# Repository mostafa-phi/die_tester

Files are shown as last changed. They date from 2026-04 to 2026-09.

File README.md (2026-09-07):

# Die-tester_Stage-control
Python script to control Suruga stages for automatic fiber alignment to TFLN waveguides

## Setup Process
- Download the code onto your computer.
- Create a .venv environment.
- Install requirements.txt
- Make sure you have OBS Studio installed (and the appropriate drivers/software for the camera)

## Running
- The workfplow will be in main.ipynb. All the classes written by Eric (me) are in the `/src` folder. All the old code is in the `/reference_code` folder.

## Design documents
- [Die handling & edge-coupling concept study](docs/die_handling_concept_study.md) — architecture concepts for high-throughput handling of singulated 10 × 6 mm photonic dies (storage, indexing, and self-registering presentation to the fiber stages).
- [Month-1 prototype plan](docs/prototype_plan_month1.md) — what to build first, parts with lead times, week-by-week schedule and pass criteria for robotic die exchange on the existing tester.
- [Pick-and-place design note](docs/pick_and_place_design.md) — how the gripper holds the die (friction on the end faces, no toe), nose geometry, the pick/place sequences at the tray and the chuck with heights, forces and interlocks, die-present sensing, what the hand-cycling rig must measure.
- [Parts list](docs/parts_list.md) — one page sorting every part into purchase, machine (with material and process) and print (PPA-CF), with the CAD file for each.
- [Print list](docs/print_list.md) — every custom part with its STL, what is printed in PPA-CF for the prototype and what is machined, print orientation, holes to ream or tap, bolts, and the order to print in.
- [Month-1 bill of materials](docs/bom_month1.md) — exact part numbers, vendors, checked prices and lead times, plus the in-house vs outsourced die-sorting decision.
- [Interactive 3-D clearance model](docs/die_handling_3d.html) — three.js scenes of the full test-station exchange (CAD layout: nest, NanoMax fiber stages, microscope, Cartesian axes, wafer tray), tape pick, tray pocket and sorting station.
- [CAD package](cad/README.md) — parametric CadQuery models, one folder per component: [gripper](cad/gripper/README.md) (end-face die gripper: STEP/STL per part, SMC MHZ2-6D, tolerances, tuning), [nest](cad/nest/README.md) (self-registering, temperature-controlled chuck-and-cage chip stage), [tray](cad/tray/README.md) (112-pocket wafer tray, print file) and [station](cad/station/README.md) (full station with vendor models, clearance checks, layout and movement pattern). `python cad/build.py` regenerates everything; `CLAUDE.md` records the design rules and the folder-synchronization requirement.

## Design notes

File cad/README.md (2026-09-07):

# CAD package: one folder per component

Parametric CadQuery models of the die-handling redesign, built and kept in sync by one script.
Frame, die, contact rules and shared helpers are in `common/`; the rules for working here are in
[`../CLAUDE.md`](../CLAUDE.md).

| Folder | What | Depends on | Outputs |
|---|---|---|---|
| [`gripper/`](gripper/README.md) | end-face die gripper module: SMC MHZ2-6D, two arms, tip blocks, flexure blade, bracket; vertical (default) and horizontal (`_h`) layouts | `common` | per-part STEP/STL, assemblies, `checks[_h].txt`, renders |
| [`nest/`](nest/README.md) | self-registering, temperature-controlled chip stage: copper vacuum chuck, Semitron cage with stop pads and guards, T-riser with TEC, on the die stage (MISUMI RMPG40W-N rotary on a Suruga KXC04015-C X stage on a KB1X1) | `common`, `gripper` | part STEP/STL, assemblies (seated / set-down), `checks.txt` incl. the moving-nest sweep, renders |
| [`tray/`](tray/README.md) | 8 × 14 wafer tray with nose-slot pockets | `common`, `gripper` | print STL, pocket check STEP, `checks.txt`, renders (full-tray STEP ignored) |
| [`station/`](station/README.md) | full station: nest, gripper, MISUMI LX20 X/Z/Y actuators with their risers, tower bracket and arm, NanoMax fiber stages, microscope, tray; clearance checks; layout and movement pattern | all of the above | `checks[_h].txt`, renders (assemblies ignored, ~100 MB) |
| `vendor/` | manufacturer STEP (tracked) and the fetch script; see `vendor/README.md` | | |

## Build

```bash
python cad/build.py            # gripper (+ _h) -> nest -> tray -> station (+ _h) + renders, writes build_manifest.json
python cad/build.py --check    # exit 1 if any source changed since the last build or a tracked output is missing / edited
```

Manufacturer STEP in `cad/vendor` is placed wherever the file exists; without it the
envelope is used and the checks say so in their first line. There is one station build (plus the
`_h` horizontal-gripper variant kept for comparison), not separate envelope and vendor builds.
Every `model.py` can also be run on its own (`python cad/nest/model.py`) while iterating, but the
manifest is only written by a full build, and `--check` (run at every session start) fails until
one has been done. Commit sources, checks, renders, small STEP/STL and the manifest together.

Needs `cadquery` (full OCP build) and, for the renders, `cadgen` from the vendored skills
(`.claude/setup_cad_skills.sh` installs both).

## Reading the checks

`checks*.txt` list axis-aligned-bounding-box separations per member pair: positive = clear by that
much, OK above the stated margin, TIGHT below it, OVERLAP negative. Each README states which non-OK
lines are intended (a stop pad touching the seated die, the gripper band passing under the
objective). Anything else is a defect to fix in the model, never in the text.

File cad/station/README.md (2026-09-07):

# Full station assembly: layout, movement pattern, compatibility

`model.py` (CadQuery) → `STEP/station_assembly[_h].step` (git-ignored, ~100 MB), `checks[_h].txt`, `renders/`.
Rebuild with `python cad/build.py` (builds the default and the `_h` horizontal-gripper variant). Manufacturer
STEP from `cad/vendor` is placed wherever the file exists and the envelope is used otherwise, so a clone
without the vendor files still builds and checks; the first line of `checks.txt` lists the
vendor files that were placed. Imports `cad/gripper`, `cad/nest`, `cad/tray` and `cad/common`; this file
only **places** the components and adds the transport axes, the two NanoMax fiber stages with holder
envelopes, the microscope envelope and the table, then computes the clearances.

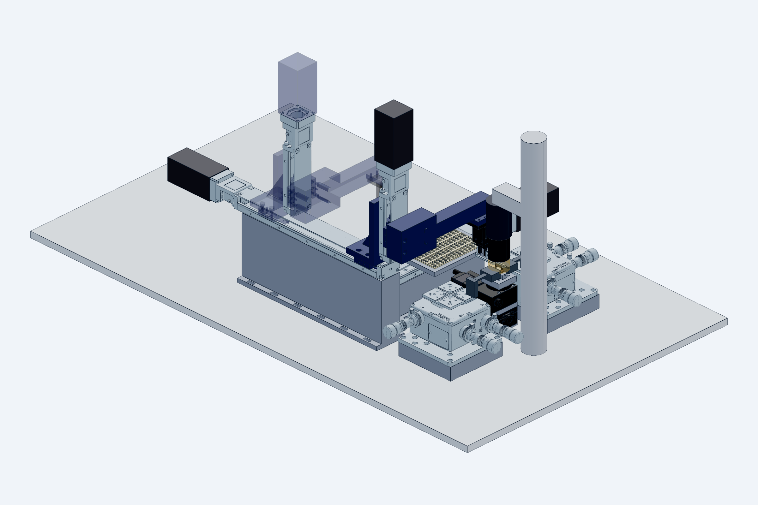
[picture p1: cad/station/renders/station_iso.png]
station

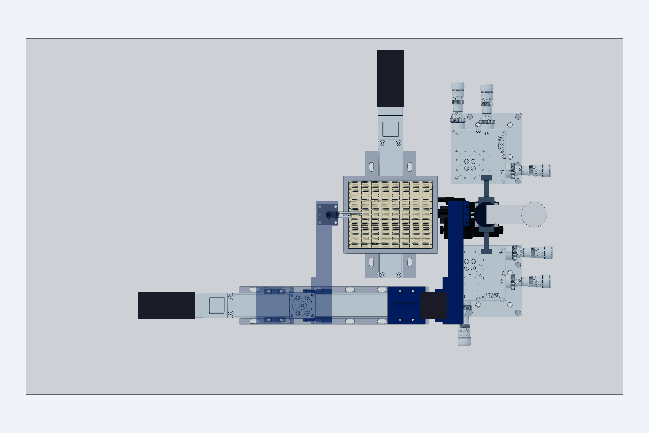
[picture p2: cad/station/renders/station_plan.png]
plan

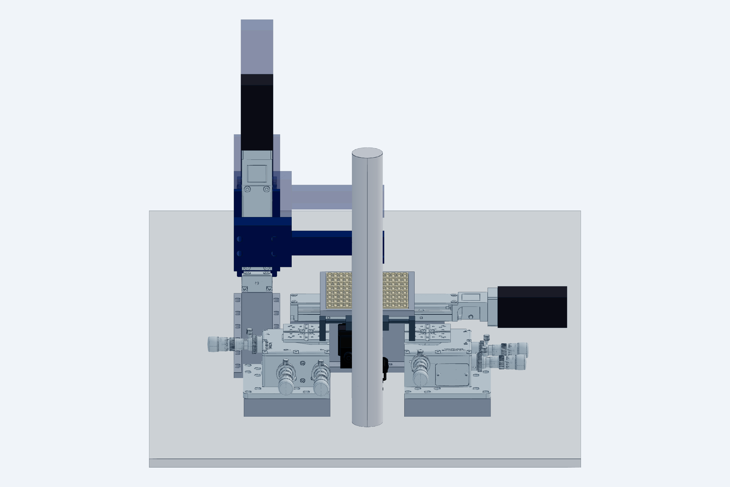
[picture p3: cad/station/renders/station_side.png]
side


## Manufacturer models

| Part | File in `cad/vendor` | Status |
|---|---|---|
| Thorlabs NanoMax 300, MAX313D/M (×2) | `thorlabs_MAX313D_M.step` | **placed**; the input stage is rotated −90° so its Z micrometer (46 mm out of the +X face) points −Y and its Y micrometers +X. A left-handed NanoMax would allow the mirror layout. |
| Thorlabs KB1X1 kinematic base | `thorlabs_KB1X1.step` | **placed** under the nest riser (25.4 × 25.4 × 12.7 mm assembled) |
| MISUMI **LX2005CG-B1-A2040-300** (X), **-200** (Y), **-100** (Z) single-axis actuators | `misumi_LX2005CG-B1-A2040-{300,200,100}.step` | **placed** (`lx_file_members()`: body with the motor-bracket casting + cover strip, table plate, adapter plate + screws; the motor is an envelope on the plate). The files confirmed the catalog reading: 40 wide × 26.5 tall body, 52 × 57 table plate to 27 above the rail bottom, screw axis at 13, bracket casting 56 beyond the rail, 40 × 40 × 13 adapter plate hanging 7 mm below the rail. Effective stroke = L − 63.5. The uploaded files carry the A2040 (□40 servo) adapter plate; the actuators are ordered with the T2042 plate for the Oriental Motor AZM46 steppers (decided; same outline). |
| SMC MHZ2-6D-M9N | `smc_MHZ2-6D.step` | **placed** through `cad/gripper` (fingers set from the drawn open position to closed) |
| Suruga KXC04015-C X stage | `suruga_KXC04015-C.step` | **placed** through `cad/nest` (motor and cable toward −X; `checks.txt` checks base, table, motor and cable loop per member) |
| MISUMI RMPG40W-N motorized rotary | `misumi_RMPG40W-N.step` | **placed** through `cad/nest` on top of the X stage (motor toward −X, long end toward −Y; straight vendor cable cut at a 40 mm lead-out; rides ±7.5 mm with the stage). The earlier RMPG60ZC-N upload is the vertical-axis type and is not used |
| Microscope objective / tube / column | — | envelope (`common.OBJ_WD`, `OBJ_DIA`, `TUBE_DIA`); measure |

The Velmex BiSlide files (`velmex_MN10-*.step`) are no longer used: the transport was re-sized to what the
handling needs (±0.15 mm at the nest, ±0.3 mm at the tray, ±0.05 mm in Z, every position approached from the
same side) and moved to the LX20 class for cost and speed; see `docs/bom_month1.md` A1.

## Layout (frame: X = die long axis, Y = optical axis, Z up, die bottom at nest = 0)

| Element | Position | Why |
|---|---|---|
| Optical table plane | Z −111 | NanoMax on a 25 mm riser + deck 62.5 + platform 4 + holder 20 puts the fiber axis at die-top height (Z 0.5); the riser exists because the die-stage stack needs 100 mm under the die. |
| Nest (`cad/nest`) on its **die stage** | T-riser neck X −8…18, Y −2…8 down to Z −12, 38 × 38 wide body to Z −22.3 on a **MISUMI RMPG40W-N** motorized rotary (axis through the die, motor toward −X, body toward −Y, on an 8 mm spacer) on a **Suruga KXC04015-C** X stage (±7.5 mm, motor toward −X) on a KB1X1; copper chuck; Semitron cage X −2.5…12.5, Y −2…8 | Narrow at the top so both fiber corridors stay open; the nest steps the die from device to device under fixed fibers; the rotary above the travel nulls the fiducial-to-fiducial yaw; the gripper meets it at stage home only. |
| NanoMax 300 (input / output) on 25 mm risers | inner faces 45 mm from the facets: Y −157…−45 and Y 51…163; X −51…61 | Fiber holders reach in from the platforms; holder fronts 5 mm from the facets. |
| Microscope | objective Ø34 centred on the die, front lens at WD 20; Ø40 tube above; arm to a Ø40 column at **X = 80** | Behind the nest, as on the bench. |
| **X actuator** (LX2005CG L 300, stroke 236.5; 208.7 used) | along X, centre-line **Y = −140**; rail X −385…−85 with its bottom at Z 7.2 on a **118 mm riser bar** (40 wide, under the base rail; the bracket casting, adapter plate and motor overhang to X −544) | Its 52 mm band (Y −166…−114, the table plate) lies beside the tray's Y sweep (deck to Y −108 at the extreme row) and beside the input NanoMax (X ≥ −51), so nothing passes under it and the riser is one bar, no bridge. Travel margins 25.3 mm at the far column, 2.5 mm after the push-to-stop. |
| **Z actuator** (LX2005CG L 100, stroke 36.5; 20 used) | vertical on a 60 × 60 × 10 angle bracket bolted to the X table plate (4 × M4); rail mounting face on the bracket's +X leg, rail Z 44…144, adapter plate and brake motor up to Z ≈ 303; table plate centre at Z 90.5 at the nest (76…112.5 available) | Only 8 mm lift + 12 mm drop are needed; the ball screw back-drives, hence the brake motor (or a pneumatic slide, see the design note). |
| **Arm** | one piece: 33-deep adapter block on the Z table plate (4 × M4 counterbored + 2 dowels), 25 mm square bar along +Y from the axis band to the die line at Z 78–103, 8 mm end plate over the gripper interface (`gripper.IFACE`) at Z 70–78 | X-table centre at the nest is **−121**: the bar starts exactly at the interface's −X edge, so there is no bar along X and no drop bar. Nothing of the arm enters the objective footprint. Static moment on the X table 0.9 N·m against 27 allowable. |
| **Gripper module** (`cad/gripper`) | actuator body X −40…−20, Y −2…8; bars 5 mm above the die | Only the two 3 mm bars and the tip blocks enter the objective footprint. |
| **Y actuator** (LX2005CG L 200, stroke 136.5; 97.5 used) + **wafer tray** (`cad/tray`) | along Y under the tray at X −146 (tray centre), rail Y −97…+103, motor toward +Y (adapter plate to Y 172, motor envelope to 262); rail bottom at Z −48 on a **63 mm riser bar**; deck on the table plate, tray ledges at **Z −12** | Columns at die X −95 … −207 (16 mm pitch), rows at 7.5 mm pitch; X selects the column, Y the row. Column 0 sits where the tray's +X rim and the deck clear the input NanoMax base as the rows sweep (21 / 13 mm). Travel margin 19.5 mm at both rows. |

`checks.txt` prints the derived numbers (rail positions, travel margins at both ends of every actuator, the
static moment on the X table plate against the LX20's 27 N·m rating, the exchange time at 200 mm/s).

## Custom mounting parts (`STEP/`, `STL/`)

The pieces between the actuators and everything else are real parts with bolt patterns (measured in the
LX20 STEP files: base holes Ø3.4 in two rows 18 mm apart on a 60 mm pitch, table plate 4 × M4 on 20 × 45 with
two Ø3 dowels) and are exported per part; the printing and finishing instructions are in
[`docs/print_list.md`](../../docs/print_list.md). Hole sizes are tap-drill / press-fit for printing.

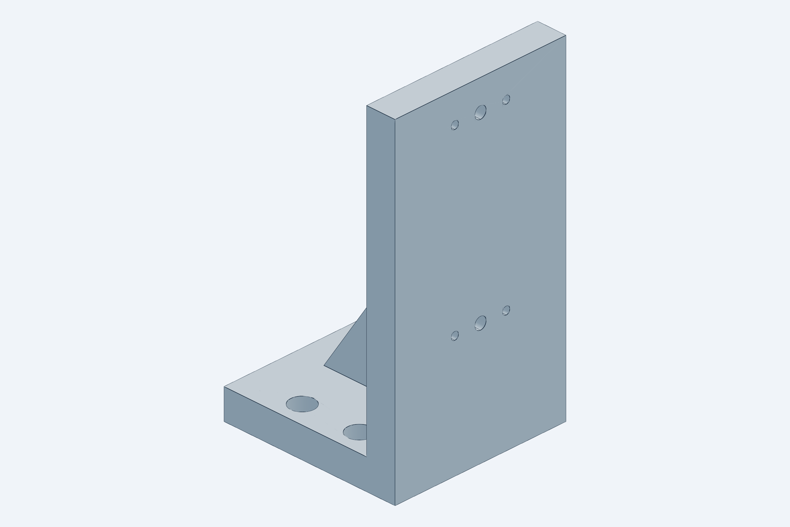
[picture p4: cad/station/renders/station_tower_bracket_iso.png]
tower bracket

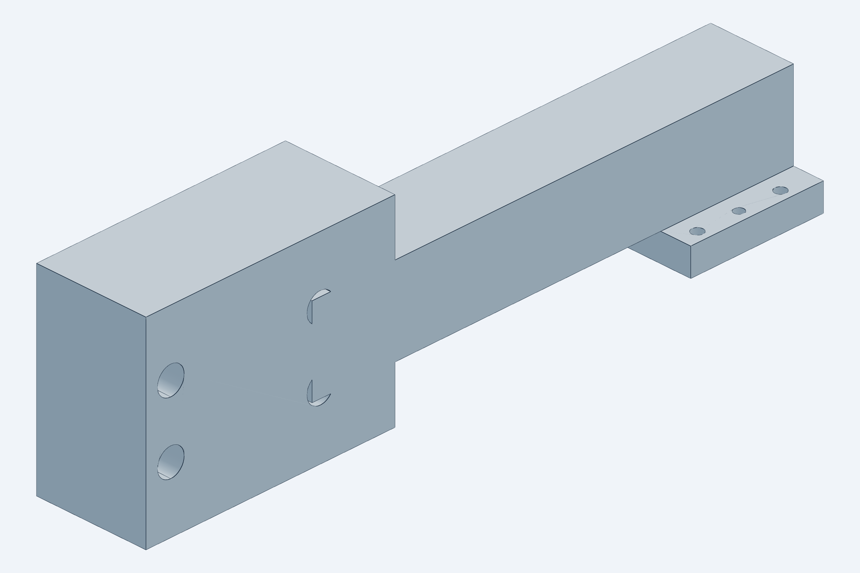
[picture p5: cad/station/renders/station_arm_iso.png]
arm

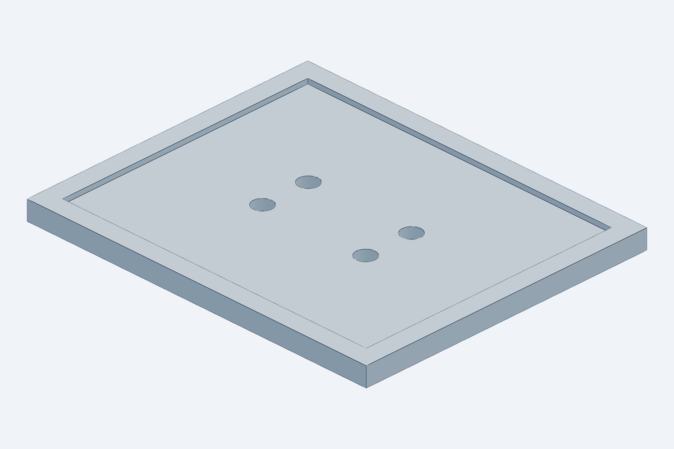
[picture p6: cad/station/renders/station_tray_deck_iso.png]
tray deck

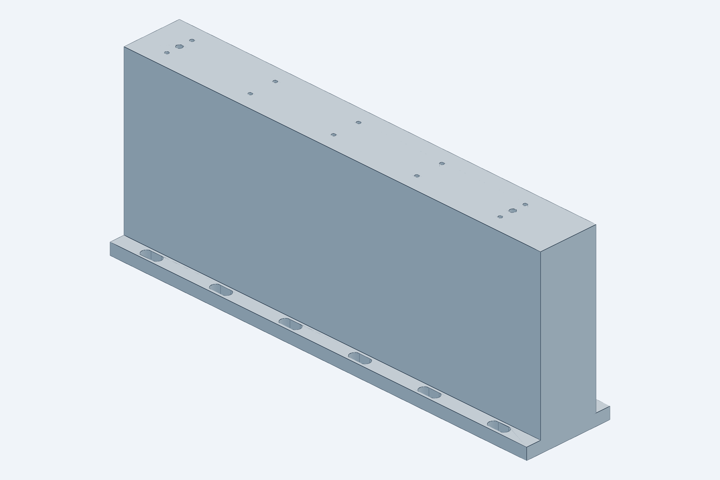
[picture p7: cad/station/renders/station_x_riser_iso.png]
X riser


| File | Part | Interfaces |
|---|---|---|
| `x_axis_riser_6061[_h]` | riser bar under the X actuator: 40 wide body from the table to the rail bottom, 60 × 8 foot flange with 6.6 × 14 slots on a 50 mm pitch | top: 10 × M3 tap-drill + 2 × Ø4 pin holes on the LX20 base pattern; foot: M6 or ¼-20 on a 25 mm / 1″ grid |
| `y_axis_riser_6061` | same under the Y actuator (80 wide flange) | 6 × M3 + 2 × Ø4; foot slots |
| `tower_bracket_6061` | 60 × 60 × 10 base on the X table plate, 10 mm leg carrying the Z rail, gusset rib | base: 4 × Ø4.5 counterbored + 2 × Ø3 dowels (table pattern); leg: 4 × M3 tap-drill + 2 × Ø4 pins (Z rail base pattern) |
| `arm_6061[_h]` | one piece: 33-deep adapter block on the Z table plate, 25 sq bar along +Y, 8 mm end plate over the gripper bracket | block: 4 × Ø4.5 counterbored Ø8 from the outside + 2 × Ø3 dowels; end plate: 4 × M4 tap-drill + 2 × Ø3 dowels on `gripper.IFACE` |
| `tray_deck_6061` | 8 mm deck on the Y table plate with a 2 mm locating pocket for the tray (0.2 mm clearance per side) | 4 × Ø4.5 counterbored from the pocket floor + 2 × Ø3 dowels |
| `nanomax_riser_6061` (×2) | 25 mm plate under each NanoMax | 16 × Ø6.6 through on the 25 mm grid (M6 bolts through the stage slots into the table) |

## Movement pattern (one exchange)

Coordinates are X-table centre / Z-table height of the arm bar / Y-stage pocket position.
Fibers are only ever moved by their own NanoMax stages.

| Step | Axis | From → to | Interlock |
|---|---|---|---|
| 0 | die stage X (KXC04015) | nest to its **home** position (stage origin sensor) | home flag set; the gripper never enters otherwise |
| 1 | NanoMax Y (both) | fibers retract 1.0 mm along ±Y | fibers-retracted flag set |
| 2 | Z | +8 mm (arm end plate Z 70 → 78), gripper open | fibers retracted, objective gap ≥ 11 mm |
| 3 | Z | −8 mm: noses descend beside the die's end faces | — |
| 4 | gripper | close (finger-on-finger stop; 0.32 N on the die) | — |
| 5 | nest | chuck vacuum off; **Z +8 mm** lifts the die | vacuum switch reads atmosphere |
| 6 | X | −121 → −216 … **−328** (column *c* of the tray: 95 + 16·c mm along the die's long axis) | Z at +8 |
| 7 | Y stage | brings row *r* to Y = 3 (±48.75 mm) | can pre-position during step 6 |
| 8 | Z | −8 −12 mm: die onto the pocket ledges (12 mm below nest height) | — |
| 9 | gripper | open (+1.5 mm per side) | — |
| 10 | Z | +20 mm; then steps 6–9 in reverse with the next die, arriving at the nest with the die's +X end face **0.2 mm short of the stop pads** | — |
| 11 | Z, gripper | Z −8 mm: die onto the chuck pad; jaws open (+1.5 mm per side) | — |
| 12 | X | **push-to-stop: gripper +1.7 mm** — the open near nose meets the die's −X end face, slides it 0.2 mm onto the two +X pads and overtravels 0.1 mm, so the blade limits the push to 0.25 N; X and yaw are now mechanical | — |
| 13 | nest, X, Z | chuck vacuum on (seat detection); gripper −1.7 mm, Z +8 mm, X out to the park position; camera pose check; fibers approach | vacuum switch reads seated |
| 14 | die stage X, θ | yaw trim: X to the fiducial at one die end, then to the other, camera reads the lateral offset, θ rotates it out (repeat once); then X steps the die ±4 mm to bring each device under the fibers (fibers realign per device; the stage stays inside the fence while the gripper is parked) | gripper parked |

Exchange time budget: ~8 s; the two X moves of 207 mm at 200 mm/s take ~1.3 s each, the rest is Z, the
jaw cycles and the vacuum settling.

## Compatibility results (`checks.txt`, vendor files placed)

All pairs are OK or TIGHT-by-design. Intended non-OK lines: the gripper band sweep passes under the
objective (that *is* the exchange; the bar-height check is `cad/gripper/checks.txt`), the stop pads touch
the seated die, and the fiber envelope 1.9 mm above the cage plate.

- **Microscope:** finger bars 12.0 mm below the objective front lens (WD 20); near head 11.0 mm;
  actuator body 8 mm outside the barrel and 5 mm outside a Ø40 tube; arm end plate and bracket 7 mm
  outside the tube; nothing within 44 mm of the column. If the tube above the objective is wider than
  Ø40, move the actuator further out with `body_cx`; the arms lengthen by the same amount.
- **Fiber stages and holders:** gripper arms 3.2 mm from the holder bodies at the nest; the X rail's nest end
  25 mm from the input NanoMax base and its band beside it in Y; the tower and the arm pass above the NanoMax
  and the holders. The die's travel path (after the 8 mm lift) clears both holders and never crosses the fiber line.
- **Die stage:** every stack member 17 mm below the holder bodies, 10 mm from the input NanoMax base and 28 mm
  from the output one; both motors, toward −X, keep 87 mm and more to the microscope column; the moving nest
  keeps 3.0 mm to the holders at the travel ends.
- **Tray side:** tray rim 21 mm and deck 13 mm from the input NanoMax base at the extreme row; the deck 6 mm
  from the X band; the tower at the farthest column clear of the Y actuator, its riser and the X motor plate;
  travel margins ≥ 2.5 mm at every actuator end (printed in `checks.txt`). The tower base plate sits 0.5 mm above
  the X body (TIGHT by design: the table plate top stands 0.5 above the cover strip).

Real collisions the model found and the layout absorbed: NanoMax Z micrometer vs X axis (input stage
rotated −90°), riser vs the 5 mm-protrusion fiber holders (10 mm neck), and, in the Velmex layout this one
replaces, the Y stage passing under the X axis (two pedestals) and the horizontal arm through the X axis
(drop bar): both disappear with the X actuator's narrow band beside the tray sweep.

## Open dimensions to measure before ordering the risers and brackets

1. Fiber axis height above the NanoMax platform (`holder_axis_above_deck`, assumed 20): sets every riser height together with the 25 mm NanoMax riser (`common.NANOMAX_RISER`).
2. Objective working distance and the diameter of whatever sits above it (`common.OBJ_WD`, `TUBE_DIA`).
3. The real fiber holder (`common.FIBER`).
4. The AZM46 motor bodies on each LX20 (the model's motor envelope is 42 sq × 90 long, which covers the AZM46MK brake motor on Z and the AZM46AK on X and Y with margin) and their cable exits.
5. KXC04015 and RMPG40W-N bolt patterns for the two adapter plates (from their STEP files); the KB1X1 platform pattern.

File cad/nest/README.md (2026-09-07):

# Nest (chip stage): self-registering, temperature-controlled

`model.py` (CadQuery) → `STEP/`, `STL/`, `renders/`, `checks.txt`. Rebuild with `python cad/build.py`.
Imports `cad/gripper` (the jaws for the clearance checks) and `cad/common` (die, contact rules,
fiber-holder envelope `FIBER`, bench levels `TABLE_Z` / `KB1X1_H`). Used by `cad/station` (`levels()`,
`stack()`, `riser()`, `chuck()`, `cage()`, `cage_parts()`, `moving_members()`, `tec()`, `N`).

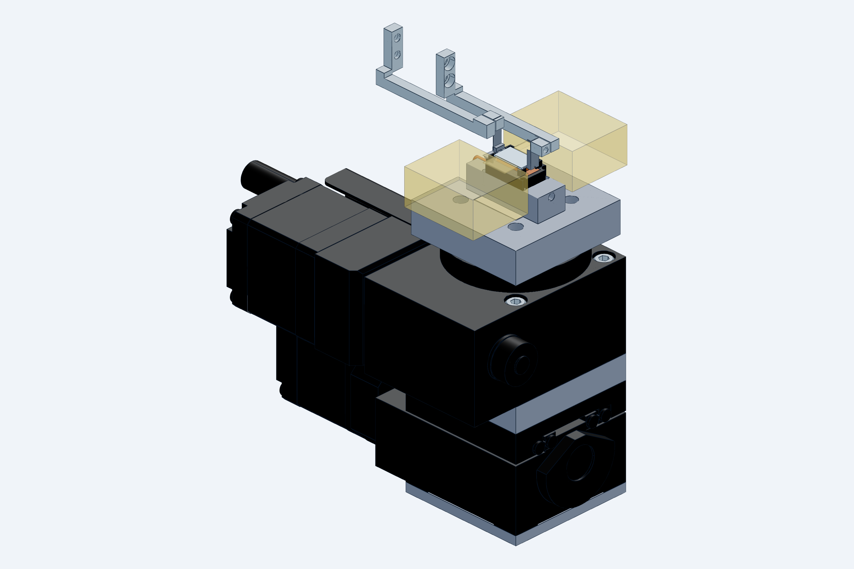
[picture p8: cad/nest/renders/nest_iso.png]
nest

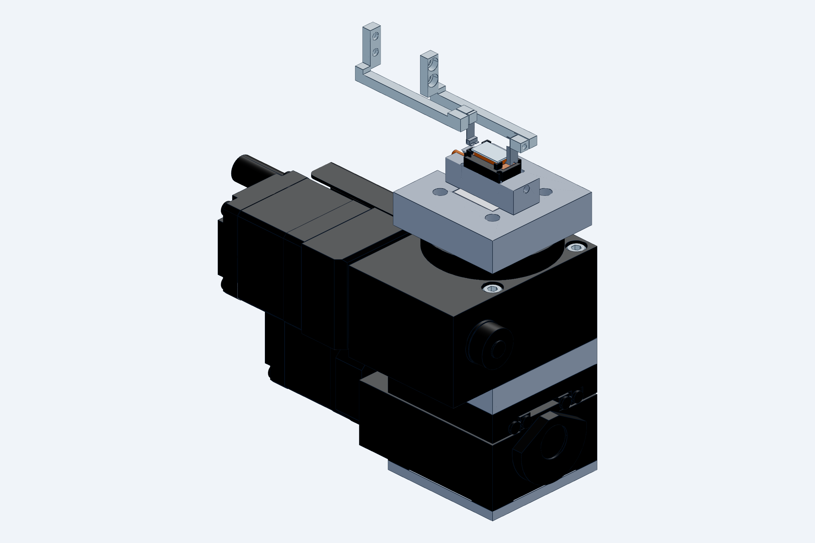
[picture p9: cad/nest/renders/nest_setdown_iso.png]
set-down, jaws open


## What it does

The gripper sets the die down on a lapped copper vacuum-chuck pad 0.2 mm short of two hard-stop pads,
opens, and pushes the die onto the pads with its own compliant nose (**push-to-stop**). The pads fix X and
yaw, the pad fixes Z, pitch and roll; Y is left free for the fiber stages (which measure the gap anyway)
and caged to ±0.6 mm. Nothing touches the facets or the top surface; only the two stop pads and the chuck
ever touch the die.

| Axis | Mechanism |
|---|---|
| Z, pitch, roll | lapped copper chuck pad (flat ≤ 3 µm), 9 × 5 mm = 75 % of the backside, 0.5 mm inboard of every edge |
| X, yaw | two Semitron ESd 480 **stop pads** on the +X end face (Y 0.6–1.2 and 4.8–5.4, 0.6 mm in from the facets, contact band Z 0.05–0.30): yaw from a 4.2 mm base ≈ 0.03° |
| Y | free; **corner guards** 0.6 mm outside each facet plane only at X ≤ 0.5 and X ≥ 9.5 where no fiber goes, plus an X guard 0.4 mm behind the −X end face |

Milling cannot make a sharp inside corner, and the die's corners are not trusted either: the stop pads
are 0.6 mm from the facets and the 0.2 mm relief between pad and guard keeps the die corner in free
space. The die registers on two pads and a plane, never in a corner.

**Push-to-stop numbers** (`checks.txt`): set down 0.2 mm short, jaws open (+1.5 mm per side), gripper
indexes +1.735 mm in X; the open near nose meets the −X end face, slides the die 0.2 mm onto the pads and
overtravels 0.10 mm, so the flexure blade limits the push to 0.25 N. Vacuum on, jaws retract. The camera
then reads Y and confirms X (a die that stuck to the chuck stops short and is caught there).

## Die stage: the nest moves

The devices span about 8 mm along the die, the NanoMax fiber stages travel only 4 mm, so the die is
stepped from device to device by moving the nest, as the current tester does with its centre stage.
One X move keeps both fibers registered to each other. The gripper meets the nest only at the stage
**home** position; the exchange sequence homes the stage first and the software fence enforces it.

The stack needs 100 mm under the die, so the two NanoMax stages and the Y stage sit on **25 mm riser
plates** (`common.NANOMAX_RISER`) and the table plane is at Z −111; the fiber axis stays at Z 0.5.

| Level (bottom up) | Part | Z (table = −111.0) |
|---|---|---|
| kinematic base | Thorlabs KB1X1 (2374-E0W), 25.4 sq × 12.7 | −111.0 … −98.3 |
| adapter | `STEP/nest_adapter_kb_kxc.step`, 6061, 3 mm: KB1X1 platform pattern → 4 × M3 tapped on the X stage's 32 × 32 base holes | −98.3 … −95.3 |
| X stage | **Suruga KXC04015-C** (crossed-roller, 40 × 40 table, 30 tall, 15 mm travel, ball screw Ø6 × 1 mm lead, 2 µm full / 1 µm half step, ±0.2 µm repeatability, 0.31 kg, 5-phase stepper on the DS102): motor section 59 mm toward −X, its 28 mm motor box 4 mm above the table top. **Vendor STEP placed** (`cad/vendor/suruga_KXC04015-C.step`): it confirms the table's 8 × M3 on a 16 mm grid with a Ø4 centre pin and the base's 4 × Ø3.5 on 32 × 32; the cable loop reaches Y +31 behind the motor, the base solid runs 11 mm further toward the motor than the catalog outline | −95.3 … −65.3 |
| spacer | `STEP/nest_spacer_kxc_rot.step`, 6061, 8 mm on the X-stage table: 4 × Ø3.4 for the rotary's M3 bolts into the table's M3 grid, Ø4 dowel at the centre (table pin hole → rotary bore) so the rotation axis sits on the die centre. Needed because the rotary's worm housing starts 2.6 mm above its base and its cable lead-out dips 2.1 mm below it, while the X stage's motor box stands 4 mm above the table top | −65.3 … −57.3 |
| rotary | **MISUMI RMPG40W-N** motorized worm-gear rotary, horizontal table, **on the X stage**: body 40 × 55 × 35 tall with the axis through the die centre, 20 mm from the short end; 39 sq table with 8 × M2 on a 10 mm grid and a Ø8 bore; 28 mm 5-phase stepper on the DS102's second axis; motor toward −X, long end toward −Y; rides ±7.5 mm with the X stage (worm housing 6.6 mm and cable 1.9 mm above the X-stage motor box at the −7.5 end). **Vendor STEP placed** (`cad/vendor/misumi_RMPG40W-N.step`) | −57.3 … −22.3 |
| riser | `STEP/nest_riser_6061.step`: 38 × 38 wide body (4 × M2 counterbored at ±10 into the rotary table, TEC pocket, wire channel) to Z −12, then the 10 mm neck to the cage plate | −22.3 … −4.5 |

**Why the rotary sits on top of the X stage.** Yaw is measured by driving the X stage from the
fiducial at one end of the die to the fiducial at the other end under the fixed microscope and reading
the lateral offset. To first order that offset is the die length times the angle between the fiducial
line and the **stage travel direction**; the travel's own angle to the bench cancels because the same
travel carries both fiducials. The rotary must therefore turn the die relative to the travel, which it
can only do above the X stage: below it, die and travel would turn together and the offset would not
change. Device stepping then shifts the next waveguide laterally by pitch × (die-vs-travel yaw) only, so
once the procedure has nulled it the fibers see no drift; the travel's residual angle to the fiber axes
(a mounting error under a degree) costs only the negligible angular coupling loss. The rotary is
motorized (worm gear, on the DS102 axis the current centre stage's θ uses), so the trim runs per die.
Dicing squareness between the end face and the facet is the floor no stage can remove. The rotary's
straight cable in the vendor file reaches 179 mm out along −X, which would run into the Y-stage riser;
it is routed down after a 40 mm lead-out (only that lead-out is modelled) and flexes ±7.5 mm with the
stage.

**Travel used.** ±4 mm of the ±7.5 available brings any waveguide at die X 1 … 9 under a fiber fixed
at station X 5. `checks.txt` sweeps the stage from −7.5 to +7.5 and reports the worst clearance of every
moving member (neck, wide body, cage plate, corner blocks, chuck, stage table) against the fixed fibers
and holder bodies: the corner blocks come within 0.4 mm of a fiber at ±4 (their tops are 0.30, 0.09 below
the fiber envelope), the neck and cage plate keep 3.0 mm to the holders at any offset, the riser keeps
5.5 mm to the motor box at −7.5. Both motors point −X because +X is the microscope column and ±Y are the
fiber stages (the station checks confirm 87 mm and more to the column, 10 mm to the input NanoMax base).

**Thermal note.** The riser's wide body is 10.3 mm thick on the rotary table, so the rotary and the
X stage become part of the TEC's hot-side path. Fine below ~2 W; above that put a copper spreader with a
thermal break under the riser or take the heat off with a water block rather than into the stage.

## Fiber access

The fiber tips protrude ~5 mm from their holders (`common.FIBER`), so the holder bodies come to Y −5 and
Y +11 (facets at Y 0 / 6), 25 mm wide, from 8 mm below to 4 mm above the fiber axis (envelope; measure
the real holder). Nothing of the nest may be in that space: the riser is a **10 mm wide neck** (Y −2…8)
from the cage plate down to Z −12, below the holders' underside, and only then widens to 26 × 26 mm for
the TEC and the KB1X1 base. Checked: cage and neck 3.0 mm from the holder faces, chuck block 5.5 mm, wide
body 4 mm under the holders; gripper arms 3.2 mm from the holders at the nest.

## Thermal and vacuum

The chuck is a C101 copper block (Ni-plated, pad lapped after plating): a 9 × 5 mm pad island on a
13 × 4.8 mm block whose neck passes through the cage plate and the riser (0.3 mm air gap all round) to a
**15 × 15 × 2.5 mm TEC** in the riser's wide section at Z −12; the aluminium riser is the hot-side heat
sink (add fins or a water block on the wide section above ~2 W). Thermistor bore Ø1.0 × 5 deep from the
+X face at Z −6. **Vacuum**: 6 × Ø0.5 holes in the pad into a 7 × 4 × 1 mm plenum, bore to a Ø1.5 stub
tube leaving the −X face at Z −6 through a clearance hole in the riser neck (no seal between copper and
riser); silicone hose to the M5 fitting.

## Parts

| File (STEP; the STL of every part is in `STL/`, see `docs/print_list.md`) | Material | Make | Notes |
|---|---|---|---|
| `STEP/nest_chuck_copper.step` | C101 copper, Ni plate | CNC + lap | pad island, vacuum holes, plenum, neck, stub tube, thermistor bore |
| `STEP/nest_cage_semitron.step` | Semitron ESd 480 | CNC | one piece: plate with the copper window, 4 corner blocks (stop pads, X guard, Y guards); 2 × M2 + 2 × Ø1.5 dowels to the riser |
| `STEP/nest_riser_6061.step` | 6061 | CNC | T-riser: neck, 38 × 38 wide body with the TEC pocket, wire channel, vacuum-stub and thermistor clearances, 4 × M3 counterbored to the KXC04015 table |
| `STEP/nest_adapter_kb_kxc.step`, `STEP/nest_spacer_kxc_rot.step` | 6061 | CNC / waterjet | 3 mm adapter plate between the KB1X1 and the KXC04015-C base (the stage's pattern confirmed in the vendor STEP; the KB1X1 platform pattern still to confirm) and the 8 mm spacer with the centre dowel between the X-stage table and the rotary |
| — | Suruga KXC04015-C X stage, MISUMI RMPG40W-N rotary, TEC 15 × 15 × 2.5, thermistor, KB1X1 (Thorlabs 2374-E0W) | buy | both stages run on the existing DS102 controller #3 (today's centre-stage X and θ axes) |

Assemblies: `STEP/nest_module_assembly.step` (die seated, jaws closed, fiber/holder envelopes, full
stack) and `STEP/nest_module_setdown.step` (jaws open at the set-down position). `checks.txt` lists every
clearance: corner blocks vs die (seated / set down / Y-offset), vs the jaws closed / open / during the
push, nest vs fiber and holder envelopes, holders vs the gripper, and the moving-nest sweep. Expected
non-OK lines: the two stop pads TOUCH the seated die (by design).

## Open items (measure on the bench)

- Real fiber-holder envelope (width, height below/above the fiber axis, front-face-to-tip): `common.FIBER`.
- RMPG40W-N resolution and repeatability from the MISUMI datasheet (not in the STEP); the KB1X1 platform bolt pattern for the adapter plate.
- TEC part number, heat load and whether the riser needs a water block.
- Die backside finish (vacuum seal on a lapped pad needs it flat and clean).

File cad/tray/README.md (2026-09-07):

# Wafer tray

`model.py` (CadQuery) → `STL/wafer_tray_8x14.stl` (the print file), `STEP/tray_pocket_check.step`,
`renders/`, `checks.txt`; the full-tray STEP (5.6 MB) is git-ignored and regenerated by
`python cad/build.py`. Imports `cad/gripper` (open jaws for the pocket check) and `cad/common`. Used by
`cad/station` (`tray()`, `extents()`, `TR` for the column positions).

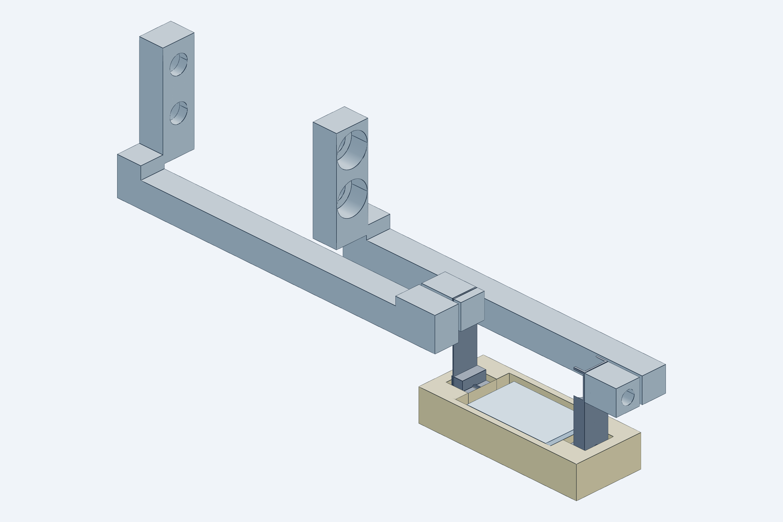
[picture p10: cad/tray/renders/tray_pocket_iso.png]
pocket with the open jaws

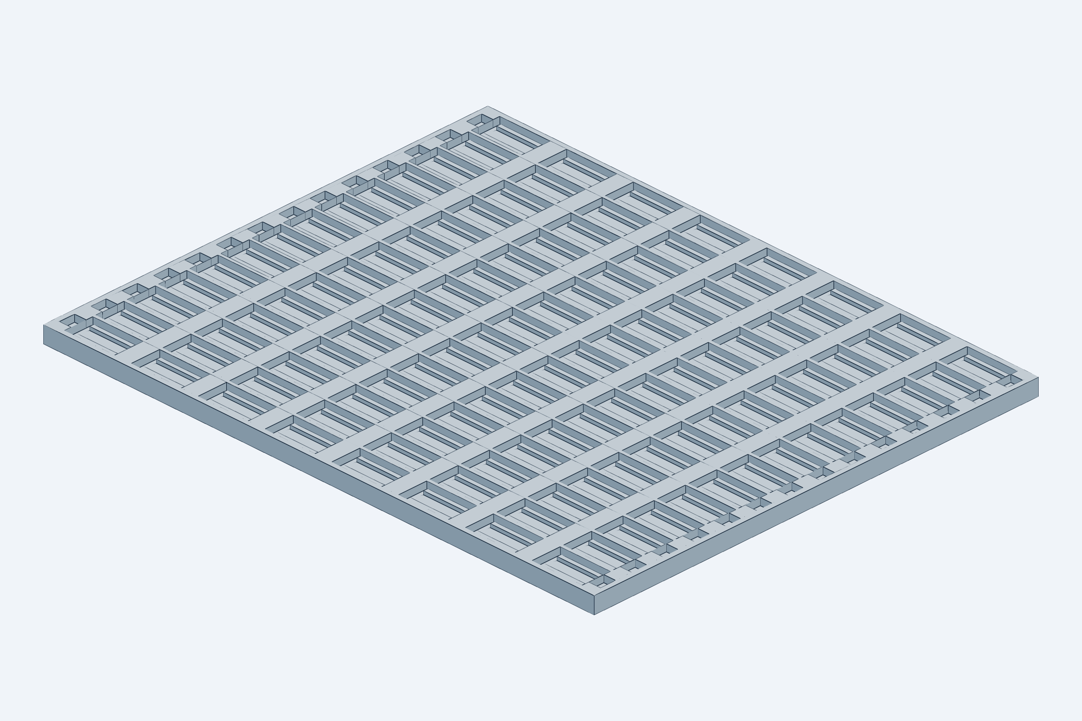
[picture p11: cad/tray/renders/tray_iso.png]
tray


## Container assumption

One 4″ wafer (~100–112 dies of 10 × 6 mm, all in one orientation) = one tray of **8 columns × 14 rows
= 112 pockets** (132 × 106 × 3.8 mm). Pocket indices mirror the wafer map, so a die's identity is its
pocket and every die returns to its own pocket after test. Physical pass/fail binning is not done at the
tester; it is a map operation at the sorting station if ever needed. SLA printed (Formlabs Rigid 10K or
Protolabs Accura), lidded, DataMatrix on the rim; fits a Form 3 bed and a 5″ wafer box. A second tray
position along X would need +130 mm X travel (Month-2 option).

## Pocket geometry

Cavity 12.0 × 6.8 mm: the die is retained to ±1.0 mm in X by its four corners against the end walls and
±0.4 mm in Y, inside the open jaws' ±1.9 mm capture. Each end wall carries a 3.6 mm wide nose slot
(Y 1.2–4.8, the contact band ±0.3) for the open jaw tip blocks; with the 16 mm column pitch the slots of
neighbouring pockets meet, so the slot is a **through channel along each column** closed only by the tray
rims, into which it runs 2.8 mm (the open tip blocks reach 3.44 mm beyond the die origin; 0.37 mm clear).
Ledges 1.0 mm wide × 0.8 mm tall under the facet-edge strips carry the die; the walls end 0.3 mm above
the die top. Nothing touches the facets or the top surface.

`checks.txt` checks one end pocket (worst case, rims on both sides) against the die and against every
open-jaw part at the set-down height; the only non-OK lines are the two ledges at exactly 0 (they carry
the die).

## Station placement

In the station the tray rides on the deck of the Y actuator with columns along X (die X of column 0 at −95,
column 7 at −207) and rows along Y (7.5 mm pitch, ±48.75 mm of Y travel); the ledges sit 12 mm below the
chuck pad. Column 0 is set by the tray's +X rim (col 0 + 15) and the deck (+8) clearing the input NanoMax
base at X −51 as the rows sweep through its Y band (21 / 13 mm). The column positions (`TR["col0_x"]`,
pitches) are read by `cad/station`, so changing them here moves the transport targets too.

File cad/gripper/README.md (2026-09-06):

# Gripper module (end-face die gripper)

`model.py` (CadQuery) → `STEP/`, `STL/`, `renders/`, `checks.txt`. Rebuild with `python cad/build.py`
(see `cad/README.md`); `python cad/gripper/model.py [--horizontal]` alone is for iteration only.
Frame, die and contact rules: `cad/common`. How the jaws are used (friction grip, sequences, forces,
interlocks): [`docs/pick_and_place_design.md`](../../docs/pick_and_place_design.md). Downstream users:
`cad/nest` (checks against the jaws), `cad/tray` (pocket vs open jaws), `cad/station` (placement, arm
interface `IFACE`).

Open `STEP/gripper_module_assembly.step` in Fusion / SolidWorks / Onshape to review; send the per-part
STEP files to the shop. The assembly includes a dimensionally faithful stand-in for the SMC MHZ2-6D
(from the SMC catalog drawing), the die and a translucent 20 mm objective keep-out cylinder.
`STEP/gripper_module_assembly_vendor.step` (git-ignored, built when `cad/vendor/smc_MHZ2-6D.step` is present)
has the real SMC body and fingers.

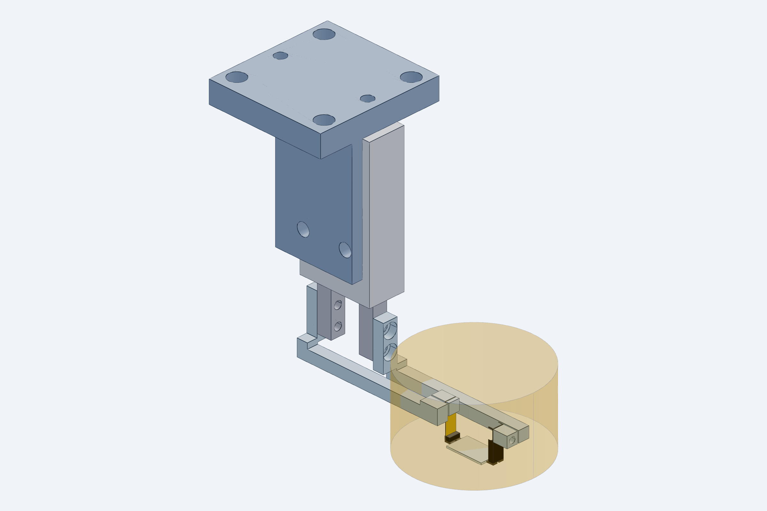
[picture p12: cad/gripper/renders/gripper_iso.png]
iso

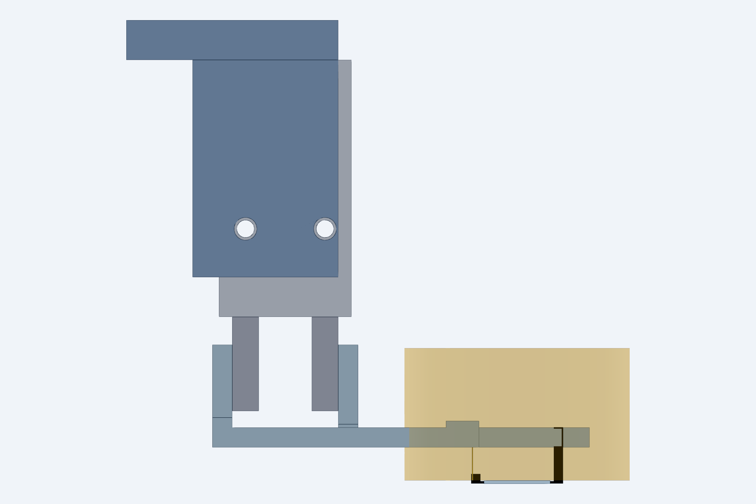
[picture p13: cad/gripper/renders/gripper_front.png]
front, looking along Y

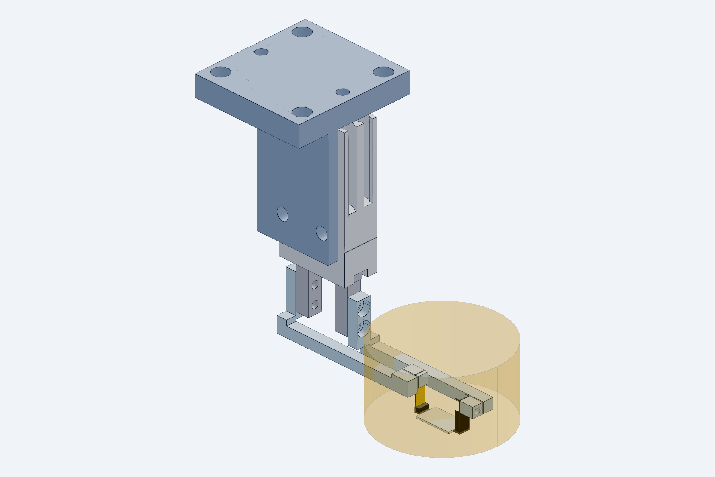
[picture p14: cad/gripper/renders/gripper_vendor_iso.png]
vendor actuator


## What the numbers say (`checks.txt`)

| Quantity | Value |
|---|---|
| Nose gap with fingers fully closed (hard stop) | 9.870 mm → blade preload 0.130 mm on a 10.000 die |
| Nose gap open | 13.87 mm (2.0 mm per side, MHZ2-6 stroke) |
| Flexure stiffness | 2.46 N/mm (0.127 mm × 3 mm spring steel, 5 mm free) |
| Grip force | 0.32 N ± 0.06 N over the ±25 µm die-length tolerance |
| Nose top below die top surface | 0.100 mm |
| Nose crown across the 3 mm band | R 30 mm, sag 38 µm at the band edges; squaring couple ≈ 0.39 mN·m per degree of die yaw |
| Friction hold vs die weight | 64 / 190 mN at µ 0.1 / 0.3 vs 1.4 mN (friction-only grip, no toe) |
| Tallest tool part inside the objective footprint | near head top, 9.0 mm above die top (far bar 8.0 mm) |
| Actuator body X extent | −40 … −20 mm (objective barrel to X −12, Ø40 tube to X −15) |
| Body Y extent | −2 … 8 mm (fiber holders at Y ≤ −5 and ≥ 11) |
| Bracket / interface plate X extent | −54 … −22 mm; 25 × 25 pattern centred at X −38, Y 3 |
| Module height, die top to interface plate top | 69.5 mm |

## Parts

| # | File | Material | Qty | Make / buy | Notes |
|---|---|---|---|---|---|
| 1 | `cad/vendor/smc_MHZ2-6D.step` | SMC **MHZ2-6D-M9N** | 1 | buy | Ø6 parallel gripper, 2 × D-M9N switches. Fingers 4 × 4 mm at ±4…8 mm from the centre when closed (8 mm gap; 12 mm open), 2 × M2 on each finger at 2.5 / 7.5 from the tip. Body mounts by 2 × M3 through-threads along Y. |
| 2 | `STEP/far_arm_6061.step` | 6061-T6, hard anodize | 1 | CNC (Protolabs/Xometry) | Rigid arm. Root plate on the far finger's +X face (2 × M2 SHCS, counterbored), transition block, 3 × 3 bar in the Y 4.8–7.8 lane, head with M2 tapped hole for the tip block. |
| 3 | `STEP/near_arm_6061.step` | 6061-T6, hard anodize | 1 | CNC | Compliant arm. Root plate on the near finger's −X face, bar in the Y −1.8–1.2 lane, raised head (top 9.0 above die) with a 0.18 × 3.1 × 3 mm blade slot and an M2 clamp screw. |
| 4 | `STEP/far_tip_block_semitron.step` | **Semitron ESd 480** | 1 (+2 spare) | CNC | 3 wide × 2 thick × 8.5 tall. Nose band 0.35 tall protrudes 0.6 toward the die at Z 0.05–0.40, crowned R 30 across its width (apex on the nominal nose plane). M2 clearance + countersink from the die side. Ø0.6 through hole at Z 0.25 for a thru-beam fiber sensor (provision; see the design note on sensing). |
| 5 | `STEP/near_tip_block_semitron.step` | Semitron ESd 480 | 1 (+2 spare) | CNC | 3 × 2 × 1.45 mm, same crowned nose, blade slot 1 mm deep from the top, Ø0.6 sensor hole. Bonded to the blade. |
| 6 | `STEP/flexure_blade_0p127_steel.step` | 0.005″ feeler-gauge stock (C1095 spring steel) | 1 (+5 spare) | cut from stock | 3.0 wide × 9.0 long (1 in block, 5 free, 3 clamped). Cut with shears, deburr, degrease. |
| 7 | `STEP/bracket_6061.step` | 6061-T6 | 1 | CNC | L-bracket: 3 mm vertical plate on the body's −Y face (2 × M3 through the body), 6 mm top plate (X −54…−22, kept 7 mm outside a Ø40 microscope tube) with 4 × M4 clearance on 25 × 25 centred at X −38 and 2 × Ø3 dowel holes. Same pattern goes on every carrier. |
| 8 | — | M2 × 6 SHCS ×4, M2 × 5 ×2, M3 × 16 ×2, M4 ×4, Ø3 × 8 dowels ×2, 0.05 mm shim stock | — | McMaster | Stainless. |
| 9 | — | Loctite EA 9460 (or Hysol) for blade-to-block bond | — | — | Cure 24 h; bond line inside the block slot only. |
| 10 | — | Gauge die 10.000 × 6 × 0.500 mm, steel or ceramic | 1 | grind | Sets switch positions and verifies the 0.10 mm top gap. |

STL files (same names) are for printing check fixtures and for quick viewing; the shop gets the STEP.

## Tolerances that matter (call out on the drawings)

- Nose contact face position relative to the arm's root-plate bolt face: ±0.02 mm on both
  arms (sets the 9.87 gap; shims correct the rest).
- Nose band height 0.35 ± 0.02; nose top at 0.40 ± 0.02 from the block bottom; crown apex on the nose plane within 0.01.
- Contact faces parallel to the root-plate face within 0.02 over 3 mm.
- Bar straightness 0.05 over the length; arms must not sag into the die (5 mm nominal
  clearance above the die top).
- Blade slot 0.18 +0.02/−0 wide.

## Assembly and tuning

1. Bolt the bracket to the actuator body (2 × M3 through the body threads), then the
   actuator+bracket to the carrier's 25 × 25 pattern with the two dowels.
2. Bolt the far arm to the far finger and the near arm to the near finger (2 × M2 each,
   0.05 mm shim pack under the far root plate to start).
3. Screw the far tip block to the far head (M2 from the die side).
4. Bond the blade into the near tip block slot; after cure, slide the blade into the near
   head slot and lock the M2 clamp screw. Check the blade hangs plumb.
5. Close the gripper on the **gauge die**. Under the microscope, verify the nose top sits
   0.10 mm below the die surface on both sides and that the nose bands touch the end
   faces over their full 3 mm. Adjust shims under the far root plate until the closed
   gap with no die is 9.87 ± 0.02 (measure with feeler gauges).
6. Grip force: rest the gripper so the near nose presses a 0.001 g pocket scale through a
   10.13 mm spacer; target 30 ± 6 g.
7. Set the two D-M9N switches at the fully open and fully closed piston positions. Die
   presence is **not** derivable from these switches (the hard stop is the same with or
   without a die); use the camera in Month 1 and the Ø0.6 fiber sensor provision later.

## Horizontal actuator layout (`--horizontal`, files with `_h`)

The alternative in which the MHZ2-6D lies along Y beside the die line (body X −40…−20, Y −44.5…−5.7,
Z 10…20, ports toward −X), the fingers point +Y toward the bars, the arm root plates hang from the finger
outer faces, and the bracket is a flat plate on the body using the actuator's vertical M3 through-threads.
Parts that change: `far_arm_6061_h`, `near_arm_6061_h`, `bracket_6061_h`; tip blocks and blade are identical.
`IFACE` (the footprint the station's arm end plate covers) changes with the layout.

| | vertical (default) | horizontal |
|---|---|---|
| bracket top plate to die bottom | 70 mm | 26 mm |
| arm crossing over the X axis | Z 82 (X slider top 65 + far-column drop 12 + 5) | same, unavoidable: the arm comes from the Z slider and must clear the X slider |
| what spans crossing → gripper | SMC body + L-bracket (the actuator is part of the load path) | one 25 mm square drop bar (56 mm) + flat plate |
| tallest part under the objective | near head, 9.0 mm above die top | same |
| far root plate to objective barrel | 7.0 mm | 7.0 mm |
| actuator body to objective barrel / tube | 7.9 / 4.9 mm | 9.4 / 40.5 mm |

The horizontal layout does **not** shorten the drop from the arm to the die (set by the X-axis slider
height); it moves that drop out of the actuator into a stiff bar and takes the actuator out of the Ø40-tube
neighbourhood. The vertical layout stays the baseline; the `_h` variant is kept building (gripper and
station) for comparison until the actuator mount is frozen. Renders: `renders/gripper_h_*.png`, `renders/gripper_vendor_h_iso.png`.

## Open items

- Confirm MHZ2-6 finger thread depth and that M2 × 6 does not bottom out (SMC drawing
  shows 4 mm fingers; use M2 × 5 if needed).
- The far bar passes over the die's Y = 6 edge at 5 mm height in the Y 4.8–7.8 lane; the
  near bar hangs over the Y = 0 edge. Both are above the fiber axis by 5 mm after a 1 mm
  fiber retract. Confirm against the measured fiber-holder height (`common.FIBER`).
- The objective must clear 9.0 mm above the die top (near head). Measure the working
  distance; if it is below ~11 mm, lower `arm_h` and shorten `blade_free` (stiffer blade
  → thinner stock, 0.004″).
- Bracket is on the −Y face; if the fiber holder on that side needs the room, mirror it
  to +Y (one parameter).

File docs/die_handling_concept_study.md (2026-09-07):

# System Redesign Study — Batch Edge-Coupled Testing of Hundreds of 10 × 6 mm Photonic Dies

**Status:** concept study for review, rev. 2.11 (CAD of the gripper, the self-registering nest on its die stage, the wafer tray and the full station with its MISUMI LX20 transport in [`cad/`](../cad/README.md))
**Scope:** ground-up redesign of the die-tester stage and handling system. The current
machine is architected around a single manually loaded die; this study treats the whole
stage system as open for redesign and asks what a machine looks like when the unit of
work is a **batch of hundreds of dies** and the target operating mode is **unattended
(lights-out) runs**, with operator involvement reduced to loading/unloading bulk
carriers and reviewing results.

Rev. 2 changes versus rev. 1: the study is reframed from "retrofit the existing
single-die stages" to a full system redesign; the carousel concept is removed; the
scaled concepts are re-derived for hundreds-of-dies batches; a recommended system
architecture is described at subsystem level. Rev. 2.1 adds the as-built observations
from the current bench (Appendix A, photo in `docs/images/current_setup.jpg`) and folds
their consequences — overhead microscope clearance, die-exchange approach direction,
fiber-arm envelope, enclosure and fiber management — into §3 and §6. Rev. 2.2 records
that the dies have **no top cladding** (exposed ridge waveguides): the nest becomes
backside-only with vision registration (§3), and §6a selects the pick-and-place system
(SCARA + backside vacuum tongue) and the slotted storage stick that goes with it.
Rev. 2.3 adds §6b: dies arrive diced on tape with kerf-width streets, so a separate
tape-to-stick sorting step (UV release, tape expansion, backside ejector, end-face edge
gripper) is defined, and the edge gripper is recorded as a candidate tester tool.
Rev. 2.4 decides on **one end-face edge gripper for every handling step**, demotes the
backside tongue to a documented fallback, and adds the sketches: sorting-station layout,
ejector/jaw pick section, contact zones with stepped-jaw detail, and nest/stick jaw
clearance (`docs/images/fig1…fig4`). Rev. 2.5 replaces the SCARA with a bench-level
3-axis Cartesian for the tester: the gripper must enter a straight ~13 mm corridor under
the objective, a SCARA's vertical quill lands where the objective barrel is, and the
articulated desktop arm first proposed for prototyping approaches from above and behind.
Rev. 2.6 sizes the storage carrier as one **wafer tray** per 4″ wafer (8 × 14 pockets; the die
returns to its own pocket) and moves the design into CAD (`cad/`). Rev. 2.7 aligns the
storage-carrier text with the tray, and records that the gripper and the complete station
(nest, NanoMax fiber stages, microscope, Cartesian axes, tray) are modelled and
clearance-checked there; the interactive model follows the same layout. Rev. 2.8 replaces
the rail nest with the self-registering, temperature-controlled **chuck-and-cage nest**
(§3) and drops the X-Y-θ correction stage. Rev. 2.9 restructures the CAD into one folder
per component (`cad/gripper`, `cad/nest`, `cad/tray`, `cad/station`, shared `cad/common`)
with a single build script that keeps them synchronized, and brings §3 and the interactive
model up to the chuck nest. Rev. 2.10 puts the nest on a **die stage**: the devices span ~8 mm
along the die and the NanoMax fiber stages travel only 4 mm, so a Suruga KXC04015-C X stage under
the nest steps the die from device to device (as the current tester's centre stage does), with a
MISUMI RMPG40W-N motorized rotary on top of it that nulls the yaw measured fiducial-to-fiducial
under the microscope; the gripper meets the nest at stage home only. The stack needs 100 mm under the die, so the
fiber stages sit on 25 mm risers. Rev. 2.11 writes down what the transfer axes actually need
(±0.15 mm at the nest, ±0.3 mm at the tray, ±0.05 mm in Z, since the die is placed by hard
references) and replaces the Velmex BiSlides with three **MISUMI LX20** actuators (lead 5 for
speed, Oriental Motor AZ closed-loop steppers with a brake on Z); the tray moves 55 mm closer to the nest and the X actuator's narrow band beside the tray
sweep removes the bridge riser. The interactive model still shows the rev. 2.10 layout.

Coordinate convention follows the brief: **X** = 10 mm die dimension, **Y** = 6 mm die
dimension (optical propagation; fibers approach along ±Y), **Z** = vertical, **θ** =
in-plane rotation.

---

## 1. Design intent: what "scaling to hundreds" actually changes

The single-die machine optimizes one coupling event. A batch machine optimizes a
*campaign*. That flips three assumptions baked into the current stage architecture:

1. **The bottleneck metric changes.** Per-die test time is
   `T_die = T_exchange + T_acquire + T_measure`. On this tester, `T_measure` for a full
   die (e.g. devices 2–66 in the current `run_all_waveguides` campaigns) is tens of
   minutes to hours; `T_exchange` is minutes. So shaving exchange seconds is not the
   prize. The prize is **removing the human from the loop between dies**, so the
   machine runs nights and weekends: a queue of 100+ dies with automatic exchange
   raises utilization from ~30 % (attended hours) toward ~90 %. For short screening
   tests (a few devices per die, `T_measure` ≈ 2–5 min), exchange and first-light time
   *do* dominate, so the design must also make exchange fast and acquisition
   deterministic. The architecture below serves both regimes.
2. **Precision should exist at exactly one point.** A carrier that replicates precision
   nests N times pays for precision N times and verifies it N times, and N is capped by
   stage travel. At hundreds scale, the winning pattern is the one used by every
   production die/wafer prober: **bulk storage is dumb and dense, transfer is coarse,
   and precision exists only at the single test site**, where one precision nest
   is made once, characterized once, and reused for every die forever.
3. **Unloading is as important as loading.** At hundreds of dies, "take the carrier off
   and sort the dies by hand" reintroduces the labor the system was meant to remove.
   The redesign must include **automatic binning** (pass/fail/grade back into output
   carriers) and per-die traceability (die ID ↔ results database).

Requirements R1–R8 from the brief (facet access, coarse-in/precise-out loading, common
optical line, independent registration, permitted contact zones, chip safety,
deterministic carrier interfaces, system-level throughput) all carry over unchanged and
are not repeated here. The presentation budget also carries over: the fixture chain
must deliver each die within roughly **±10–25 µm in Y/Z and ±0.05° in θ** of nominal at
the test site, so first light is a verification, not a search.

---

## 2. Functional architecture of the redesigned machine

Four decoupled subsystems, following the brief's storage / transfer / presentation
split, plus the optical engines:

```
   BULK STORAGE            TRANSFER              PRECISION            OPTICAL
   (hundreds)              (coarse)              PRESENTATION         ENGINES
┌────────────────┐    ┌────────────────┐    ┌────────────────────┐   ┌──────────────┐
│ input carriers │ →  │ robot / feeder │ →  │  ONE test nest at  │ ← │ 2× fiber     │
│ output bins    │ ←  │  ±0.3 mm class │ ←  │  the optical site  │   │ aligners +   │
│ (hotel/elev.)  │    │                │    │  (vision-regis-    │   │ vision       │
└────────────────┘    └────────────────┘    │  tered, §3)        │   └──────────────┘
                                            └────────────────────┘
```

- **Bulk storage** holds dies in dense carriers (slotted sticks / pallet cassettes, per
  concept) in an input **hotel** (stacked shelves with an
  elevator or a flat deck), plus output positions for binning. Capacity target:
  ≥ 200 dies resident.
- **Transfer** places the selected die into the test nest and returns it after test.
  It needs only ~±0.3 mm, ±1° placement accuracy — vision registration at the nest closes
  the rest. This is deliberately a cheap, robust motion system, not a precision stage.
- **Precision presentation** is one nest (§3) that registers X and yaw mechanically
  (push-to-stop), leaves Y to vision and the fiber stages, and steps the die along X from
  device to device on a short-travel stage under it (rev. 2.10).
  No long-travel precision axis exists anywhere in the machine: the die never travels
  far while registered, and nothing precise ever moves far.
- **Optical engines**: the two fiber aligners (each XYZ + fine alignment) and machine
  vision. Because the die always appears at the *same* nest within tens of µm, the
  fiber stages work around one fixed nominal point for the entire life of the machine —
  which is also what makes fast piezo-assisted alignment and pre-computed approach
  trajectories practical.

The reference hierarchy collapses to its shortest possible form:
`machine base → nest datums → die → waveguide` — no removable precision carrier in the
chain at all in the primary concept.

---

## 3. The precision test nest (single copy, heart of the machine)

**Governing constraint (rev. 2.2):** the dies carry **air-clad ridge waveguides — no
top oxide**. The top surface is untouchable everywhere, and the facet edges, where the
exposed waveguides terminate, are the most fragile lines on the part. The nest and
every handling step therefore contact the die only on its **backside** (rails, ledges,
ejector pins) and, for transfer, on the **middle of its two non-optical X-end faces**
(gripper jaws, §6a, Fig. 3). In-plane registration at the nest is done by **vision**,
not by side datums: with a single fixed nest and a calibrated overhead camera, a
measured X/Y/θ is as good as a mechanical one and carries zero facet risk. This
supersedes the brief's facet-face datum sketch (§9 of the brief).

*Rev. 2.8/2.9 (CAD of record: [`cad/nest`](../cad/nest/README.md)): X and yaw are now registered
mechanically after all — not on the facets but on the **non-optical +X end face**, by two
hard-stop pads the gripper pushes the die against with its own 0.25 N compliant nose (the
same end-face band the jaws use). Y stays free, read by the camera and absorbed by the fiber
stages, and is caged to ±0.6 mm by corner guards that stand outside the facet planes only
where no fiber ever goes. The X-Y-θ correction stage is dropped; the nest sits on the
kinematic base. The two vacuum rails of rev. 2.2–2.7 are superseded by a lapped **copper
vacuum chuck pad** with a TEC under it. The rails still appear in Fig. 4 and in the older
figures; the geometry of record is the CAD.*

One nest, machined and lapped once, characterized exhaustively (chuck-and-cage, rev. 2.9):

```
 Top view (die transparent)                                Side view (looking along X)

   Y=8   ┌────────────────────────────────┐ cage plate    fiber →                  ← fiber
         │ ▪ Y guard            Y guard ▪ │ (Semitron)      ┃    die 0.5 thick        ┃
   Y=6 ──│───────────── facet ────────────│──        holder ┸┌──────────────────────┐┸ holder
         │▪┃   ┌────────────────────┐   ┃▪│ ← stop pad  Y −5 │  DIE                 │ Y +11
         │ ┃   │  · · ·  chuck pad  │   ┃ │   (Y 4.8–5.4) ───┴─┬──────────────────┬─┴───  cage plate
         │X┃   │  9 × 5 mm, lapped  │   ┃ │                    │ copper pad 9 × 5 │       Z −1.5
         │ ┃   │  · · ·  6 vac holes│   ┃ │ ← stop pad         │   plenum, holes  │
   Y=0 ──│▪┃───│──────── facet ─────│───┃▪│── (Y 0.6–1.2)      │  copper neck     │  10 mm wide
         │ ▪ Y guard            Y guard ▪ │                    │  (riser neck)    │  down to Z −12
   Y=−2  └────────────────────────────────┘                 ═══╧══════════════════╧═══ TEC 15 × 15
         X=−0.4  X=0             X=10  X=10.6              wide riser / heat sink below the holders
         X guard                   +X stop pads
```

- **Support and hold-down (Z, pitch, roll — mechanical):** a lapped (≤ 3 µm) **copper
  chuck pad** 9 × 5 mm, 0.5 mm inboard of every die edge, so 75 % of the backside rests on
  metal; six Ø0.5 vacuum holes into a plenum in the copper block. The pad defines the die
  plane to microns — exactly the degrees of freedom vision measures poorly. The pad top is
  0.5 mm below the waveguide plane; the cage plate around it is 1.5 mm lower still and
  never in a fiber's path. Vacuum level doubles as **presence/seat sensing**.
- **Thermal:** the chuck is the top of a Ni-plated C101 copper block whose neck passes
  through the cage plate and the riser (0.3 mm air gap) to a **15 × 15 × 2.5 mm TEC** at
  Z −12; the aluminium T-riser is the hot-side sink. A thermistor bore enters from +X. The
  die can be temperature-controlled at the nest without any part touching its top or facets.
- **Fiber access:** the fiber tips protrude only ~5 mm from their holders (25 mm wide,
  Z −8…+4 around the fiber axis), so the holder bodies come to Y −5 and Y +11. The nest is a
  **10 mm wide neck** (Y −2…8) from the cage plate down to Z −12, below the holders'
  underside, and widens only there. Nothing stands where a fiber can go (X 1…9 in front of
  either facet).
Fig. 4 — jaw clearance at the nest and in a stick pocket (rev. 2.4 sketch: rails; the nest of record is the chuck above)

- **Jaw clearance at the die ends (Fig. 4):** the transfer tool grips the die by its
  two non-optical X-end faces (§6a), so the nest leaves the ends free except for the
  0.6 mm stop pads and the 0.4 mm-gap X guard, all below Z 0.40; the jaw noses descend
  outside them (checked closed / open / during the push in `cad/nest/checks.txt`).
- **In-plane registration — X and yaw mechanical, Y by vision:** two **Semitron ESd 480
  stop pads** on the +X end face (Y 0.6–1.2 and 4.8–5.4, 0.6 mm in from the facets, contact
  band Z 0.05–0.30, yaw from a 4.2 mm base ≈ 0.03°). The gripper sets the die down 0.2 mm
  short of the pads, opens, and indexes +1.7 mm: its open compliant nose slides the die onto
  the pads and overtravels 0.1 mm, so the flexure limits the push to **0.25 N**
  (**push-to-stop**). Milling cannot make a sharp inside corner and the die's corners are
  not trusted either, so the die registers on two pads and a plane, never in a corner: the
  pads sit 0.6 mm from the facets with a 0.2 mm relief to the guards. Y is free, read by the
  overhead camera (the existing OpenCV template/edge methods in `ChipAlignmentController`)
  and absorbed by the fiber stages' own Y travel; four **corner guards** 0.6 mm outside the
  facet planes at the die corners only (X ≤ 0.5 and X ≥ 9.5) and an X guard 0.4 mm behind
  the −X end face cage the die so it cannot leave the pad, and touch nothing in normal
  operation. The facet faces are never a datum surface.
- **Die stage (rev. 2.10):** the nest sits on a Suruga KXC04015-C X stage (15 mm travel,
  1 µm half step, on the existing DS102) that steps the die ±4 mm so every device comes under
  the fibers, which then realign per device; one X move keeps both fibers registered to each
  other, exactly as the current tester works. On top of it a MISUMI RMPG40W-N motorized worm-gear
  rotary (on the DS102 axis the current centre stage's θ uses) turns the die relative to the
  travel: after loading, the X stage brings the fiducial at one die end and then the other under
  the microscope, the camera reads the lateral offset, and the rotary nulls it. That offset is the
  die's yaw relative to the travel (the travel's own angle cancels), which is why the rotary has to
  sit above the X stage, not below it. Per-device realignment needs only ~0.1° of yaw; open-loop
  stepping needs ~0.02°, which the motorized trim makes possible. The gripper meets the nest at the stage's home position only, enforced by the
  fence. The stack needs 100 mm under the die, so both fiber stages and the Y stage sit on 25 mm
  riser plates. Stack and clearances: [`cad/nest`](../cad/nest/README.md).
- **Exchange sequence per die:** die stage to home → fibers retract (interlocked) → jaws
  descend beside the outgoing die's end faces, close, chuck vacuum off, lift → carry to its
  tray pocket → return with the incoming die → lower onto the chuck 0.2 mm short of the pads,
  jaws open, push-to-stop, chuck vacuum on, jaws retract and rise → camera confirms X against
  the pads and reads Y → fibers approach → die stage steps device by device.
- **No structure above the die top surface** in the central 8 mm of X, no structure at
  waveguide height anywhere in the ±Y fiber approach cones, and a software/hardware
  interlocked fiber-retract corridor before any nest actuation (carries over R1/R5/R6
  and brief §15/§22 unchanged).
- **Envelope as it exists today (Appendix A):** the fibers arrive on long, thin
  cantilevered holder arms that pass through slots in the ±Y walls of the present
  enclosure, and the die sits under a high-magnification objective a short working
  distance above it. Three consequences for the nest: (i) the ±Y corridors must be
  sized for the *arm*, not the fiber — the current arms are tens of mm long with a
  V-groove clamp near the tip, so the pedestal recess and any nest wall on the ±Y sides
  are set by clamp height/width, not by the 125 µm fiber; (ii) the only free approach
  directions to the die are **±X** (horizontally, under the objective) and **from
  above** (only if the objective retracts), which fixes the die-exchange geometry in §6;
  (iii) the nest must be low and stiff — the present chuck rides a tall stage tower,
  and a low pedestal directly on the base both shortens the structural loop to the
  fiber stages and frees vertical room for the exchange mechanism.

Everything else in the machine can be ordinary industrial automation because this one
component absorbs the precision problem.

---

## 4. System concepts at hundreds-of-dies scale

Three full-system concepts plus one deliberate inversion. All share the §3 nest; they
differ in storage format and transfer mechanism — which is exactly where the brief says
the freedom is.

### S1 — Stick hotel + Cartesian pick-and-place into the fixed nest  *(recommended)*

**Storage:** dies sit in **slotted carrier sticks** (§6a) whose pockets support the die
on its backside only and leave a channel under the center open at both ends. A hotel
deck holds 6–10 sticks (input, pass, fail, regrade) — ≥ 100–200 dies resident. Sticks
are loaded at a bench, ideally by the dicing vendor.

**Transfer:** a bench-level **3-axis Cartesian** (motorized linear stages, µm class)
carrying a stepped-jaw **end-face edge gripper** (§6a, Fig. 3) on a low arm that takes the
die by the middle of its two non-optical X-end faces, lifts it off the pocket ledges or
nest rails, and carries it. No top-surface or facet contact at any point. Placement
scatter of a few tenths of a mm in Y is closed by vision registration at the nest; X
and θ are already defined by the jaw faces.

**Sequence per die:** fibers retract → gripper removes die *i* from the nest → returns
it to its tray pocket → picks die *i+1* → sets it on the nest chuck → jaws open, push-to-stop
onto the +X pads, chuck vacuum on → overhead camera confirms X and reads Y → fibers
approach along the pre-computed trajectory → first light as verification → measure. In
the screening regime a second gripper pre-stages die *i+1* so the swap itself is ~5 s.

**Why it wins at this scale:**
- Operator interaction = swap packs and press start: **one interaction per ~100–200
  dies**, and runs continue unattended overnight.
- Automatic binning and per-die traceability (pack + pocket ID ↔ results) fall out of
  the architecture for free.
- Exactly one precision component; adding capacity = adding shelf positions, which are
  free.
- Failure containment: a mis-seated die is detected by vacuum/vision *before* fibers
  approach; the die is returned to a reject position and the run continues — no human
  needed for the common faults.

**Main risks:** it is a real machine build (robot, hotel, gripper tooling, guarding,
ESD/ionization, error-recovery software); every die is robot-handled twice — mitigated
by backside-and-end-face-only contact, low approach velocities, and the fact that robot handling
replaces *tweezers*, historically the worst offender; custom sticks must be adopted
upstream; total cost dominated by the robot cell (order €30–60 k in COTS hardware
before integration labor).

### S2 — Pallet cassette line (SMT-feeder pattern)

**Storage:** each die is mounted **once**, at an offline bench station with its own
self-registering fixture, onto a reusable ~16 × 16 mm hardened **pallet** carrying
ground datum features and a clip/latching hold. Pallets stack ~25–50 high in gravity
**cassettes**; several cassettes = hundreds of dies queued.

**Transfer:** a simple elevator + pusher (walking-beam class mechanics, no robot)
advances one pallet at a time into a **kinematic dock** at the optical site: 3-groove
mount + clamp, ~1–2 µm repeatable. Tested pallets are pushed on into output cassettes
(binning by gate = two output cassettes minimum).

**Strengths:** bare-die handling happens exactly once per die, at a bench with ideal
ergonomics and lighting — the lowest facet-risk concept; the tester-side automation
handles only robust identical steel objects, so it is *simpler and more reliable* than
a bare-die robot; pallet serial numbers give bulletproof traceability; scaling is
linear (more cassettes).

**Weaknesses:** the per-die pallet-mounting labor is real (~30–60 s/die at the bench) —
it relocates rather than removes the per-die human touch, unless a second loading
automat is built later; a pallet fleet of 300+ units is a recurring cost (tens of € per
pallet at quantity) and a management task (cleaning, inspection); one extra tolerance
interface (die→pallet→dock) versus S1's die→nest.

**Best fit:** if §8 measurements or early trials show that *any* robot handling of bare
dies is unacceptable for facet yield, S2 is the scaled architecture of choice.

### S3 — Batch comb plates on a long-travel transport  *(semi-automated fallback)*

The linear self-registering magazine of the brief, scaled as far as it goes: a
**300–400 mm travel transport axis** carrying 2–4 removable monolithic comb plates of
12–15 nests each (~25–60 dies per load), each comb kinematically mounted, loaded
offline at a bench station, both ±Y corridors open along the full row.

This is the least machine-building of the three: no robot, no feeder, ~1/5 the
integration effort of S1. But it fundamentally cannot reach the campaign goal alone:
precision is replicated ~50× instead of 1×; capacity is capped by transport travel;
there is no automatic binning; and an operator event is still needed every ~50 dies, so
overnight runs end when the combs do. **Role in the redesign:** the engineering-lot /
bring-up mode and the risk-reduction stepping stone — the nest design, vision verify,
fiber choreography, and orchestration software developed for S3 transfer 1:1 to S1
(same nest, same software, the robot simply replaces the transport axis). Not the end
state.

### S4 — Stationary die field + translating optical head  *(evaluated, not selected)*

The inversion the brief asks about, evaluated clean-sheet rather than against legacy
software: dies rest in large fixed comb fields; both fiber aligners + cameras ride a
long gantry. Even with a from-scratch design this loses on physics, not on software
legacy: the moving payload is two opposed fiber stacks whose *mutual* alignment must
survive translation (the hardest stiffness/metrology problem available), optical fibers
and cabling live in drag chains (polarization and loss instability injected directly
into the measurand), and the precision problem is replicated across every nest in the
field *and* the gantry. It becomes attractive only if dies must sit on infrastructure
that cannot move (temperature-controlled chuck, RF probe cards on every die). Recorded
with that trigger condition; otherwise rejected.

---

## 5. Comparison at hundreds-of-dies scale

Ratings: ● strong / ◐ adequate / ○ weak.

| Criterion | S1 hotel + Cartesian + 1 nest | S2 pallet cassette line | S3 batch combs | S4 moving head |
|---|---|---|---|---|
| Dies resident per operator interaction | 100–200 ● | 100–400 (cassettes) ● | 25–60 ◐ | 25–60 ◐ |
| Operator minutes per 100 dies | ~5 (stick swaps) ● | ~60–100 (pallet mounting) ○ | ~30 (comb loading) ◐ | ~30 ◐ |
| Unattended (lights-out) capability | full ● | full ● | until combs exhausted ◐ | until field exhausted ◐ |
| Number of precision feature sets | 1 ● | 1 dock + pallet fleet ◐ | ~50 nests ○ | ~200 nests + gantry ○ |
| Die-to-die Y/θ consistency | best possible (one nest) ● | dock-limited ● | comb machining ◐ | comb + gantry metrology ○ |
| Automatic binning / traceability | native ● | native (2+ cassettes, serials) ● | none ○ | none ○ |
| Bare-die handling events per die | 2 robot touches ◐ | 1 bench mount ● | 1 bench load ● | 1 bench load ● |
| Facet-risk profile | robot near facets, gated ◐ | lowest ● | low ● | fibers translating over dies ○ |
| Exchange time (short-test regime) | ~15–25 s, pipelined ● | ~10–20 s ● | ~10–20 s ● | ~20–40 s ◐ |
| Error containment / recovery | auto-reject, run continues ● | auto-gate ● | skip nest, human sorts later ◐ | ○ |
| Mechanism reliability class | robot cell ◐ | pusher/elevator, simplest ● | single axis, simplest ● | long gantry + drag chains ○ |
| Integration effort / relative cost | ~5× (baseline = S3) ○ | ~3× ◐ | 1× ● | ~8× ○ |
| Incremental path from S3 | direct (same nest, same s/w) ● | dock ≠ nest, partial ◐ | — | none ○ |
| Scalability beyond hundreds | add shelves ● | add cassettes ● | capped by travel ○ | capped by field ○ |

---

## 6. Recommended system: S1, reached through S3's nest

**End state (the machine to design toward):**

- **Base:** granite or polymer-granite machine base; thermal enclosure; ionized-air ESD
  environment; light curtain / interlocked doors around the robot volume.
- **Optical site:** the §3 chuck-and-cage nest on its kinematic base, fixed near the
  center of the base. Overhead verify camera (die pose, existing OpenCV template/edge
  methods carry over); optional side cameras on the fiber aligners for gap/facet view.
- **Fiber aligners (redesigned, both sides):** stacked coarse XYZ (the DS102-class
  stepper stacks are adequate here and can be retained *as components*) + **piezo
  flexure XYZ fine stages** (~100 µm range, nm resolution) for fast raster/gradient
  alignment. With the die always at the same nominal point, approach trajectories are
  pre-computed and first light typically completes in seconds. Fibers park in a
  retracted, interlocked position during every nest/robot action.
- **Vision column (redesigned around the exchange):** the overhead objective stays —
  it is the verify camera — but it must **clear the exchange volume**. Two options,
  chosen by the objective's working distance and the end-effector height: (a) put the
  microscope column on a motorized Z lift (or a pneumatic two-position retract) that
  raises it 50–100 mm during every exchange; (b) keep it fixed and use a *long*
  working-distance objective (≥ 30 mm) with a low-profile end-effector that enters
  horizontally along ±X beneath it. Option (b) removes a moving element from the
  optical path and is preferred if the magnification budget allows; (a) is the
  fallback; (c) since the present column can be **rotated away by hand**, motorize that
  pivot (a stepper or pneumatic rotary with a hard stop) and swing the objective clear
  for every exchange. With the gripper module of §6a the only tool parts under the
  objective are two thin finger bars, ~3 mm tall at 5 mm above the die top, so option
  (b) needs a working distance of only ~11 mm and is the baseline; option (c) is the
  fallback for short-WD objectives and is harmless to vision registration **provided
  the die pose is measured relative to nest fiducials in the same image**, which makes
  the pivot's return repeatability irrelevant. It costs ~2–5 s per exchange and one
  more interlocked mechanism. In every case the objective-to-die gap (or the
  swung-clear state) is a hard interlock input for the transfer axes, exactly like
  fiber retract.
- **Transfer:** a bench-level **3-axis Cartesian** beside the optical table, carrying the
  stepped-jaw **end-face edge gripper** on a low horizontal arm that enters under the
  objective along X — the only direction not occupied by fiber arms (±Y) — descends
  beside the die's end faces, grips their middles and lifts the die off its rails. Selection rationale, tool geometry and alternatives
  are in §6a. The fiber arms park retracted and the objective gap is confirmed before
  the jaws may descend; all states are interlocked.
- **Storage:** custom **carrier sticks** (§6a, Fig. 4) whose pockets present the same
  backside ledges and end-face jaw slots as the nest, so the gripper picks from storage
  and places into the nest with one motion primitive. 6–10 sticks on a hotel
  deck with stick-ID reading (DataMatrix); designated output sticks for binning.
  Located to one side of the optical site along **X**, so the robot's transit path
  never crosses the fiber corridors. Standard waffle packs are not used on the machine
  (closed pocket floors force a top pick).
- **Enclosure and dressing (replaces the present small box):** the current 3D-printed
  enclosure with glass top and acrylic front shows the need for still air and dust
  control already exists; in the redesign it grows into the full cell — one enclosure
  around nest, fiber aligners, robot and hotel, with a laminar top-down flow or at
  least a still-air lid, interlocked doors, ionized air, and windows placed for the
  overhead camera and operator view. Fiber pigtails and stage cables, which today lie
  loose on the breadboard, are routed in captive guides with strain relief on the
  aligner frames: a robot may never share a volume with an unmanaged fiber. Fiber
  aligners mount to the same rigid base plate as the nest rather than to the optical
  table individually, closing the metrology loop through one stiff part.
- **Software (this repo evolves into the orchestrator):** a campaign layer above the
  existing per-die stack — die queue + results database keyed by pack/pocket ID; state
  machine per die (stored → picked → verified → nested → measured → binned) with
  explicit recovery transitions; the existing `FirstLightController` /
  `WaveguideAlignmentController` become the "measure" state's engine; `SoftwareFence`
  logic generalizes into the fiber/robot interlock. The current codebase's
  per-waveguide automation is the one part of the present system that transfers to the
  redesign essentially intact.

### 6a. Pick-and-place system and die pickup

**How a die is picked up — one tool everywhere (rev. 2.4): the end-face edge gripper.**
The gripper is a **self-contained module** — actuator, flexure fingers, position
switches, valve — with a plain bolt-and-air interface (one plate, four screws, one air
pair, one sensor cable). The same module bolts to the Cartesian Z-arm at the tester,
to the sorting-station head, and, if ever needed, to a fallback robot's flange through
an adapter plate. It is engineered once, separately from whatever carries it, because
it is the only part every handling step shares. Its actuator body sits **outboard at
X ≤ −16 mm**, outside the objective footprint; only two thin cantilever finger bars
(~3 mm tall, ~5 mm above the die top) and the noses ever enter the space under the
objective (3-D model, nest scene).
Because the top surface carries exposed waveguides and the facet edges are fragile, the
die is gripped only by the **middle 3 mm of its two non-optical X-end faces**, and is
otherwise supported only on its backside (ejector pins, nest rails, stick ledges). The
same gripper picks from tape at the sorting station (§6b), exchanges dies at the nest,
and bins them into sticks. Geometry in Figs. 2–4:

- **Jaws:** parallel micro-gripper (pneumatic or voice-coil, with jaw-position feedback
  for die-present / no-die detection), PEEK or Vespel jaw inserts, dissipative grade —
  LN is pyroelectric and charges with every temperature swing; the cell is ionized.
  One jaw is compliant in yaw (±2°) so both faces seat on a die whose end faces are not
  perfectly parallel.
- **Stepped jaw (Fig. 3 detail):** the contact nose is 0.35 mm tall and its top sits
  **0.10 mm below the die's top surface**; the jaw body is set back 0.6 mm above the
  nose. The jaw therefore cannot overhang the surface geometrically, whatever the
  closing force. This requires the die's top-surface height to be known to ~±50 µm
  wherever it is gripped — i.e. known support heights plus a die-thickness spec.
- **Contact zone (Fig. 3 plan):** the jaws touch the end face only over its middle
  3 mm (Y = 1.5…4.5), staying ≥ 1.5 mm from the facet corners. Facet faces, facet edges
  and the top surface are never touched by anything.
- **Forces:** grip 0.2–0.5 N. Contact pressure on a 0.35 × 3 mm patch ≈ 0.3 MPa. Euler
  buckling load of the 10 × 6 × 0.5 mm die under end load ≈ 1 kN. Friction hold
  (µ ≈ 0.4) ≈ 0.2 N against a die weight of ~1.4 mN — >100× margin at any sane
  acceleration.
- **What the jaws give for free:** X and θ are fixed mechanically by the jaw faces
  while the die is held (centering gripper), so placement scatter at the nest is
  ~±0.02 mm in X and ~±0.1° in θ; vision then corrects mostly Y.
- **Fallback (documented, not built unless trials fail):** a thin backside vacuum
  **tongue** (≈ 2.5 × 0.8 mm) sliding along X in the gap between the rails, lifting the
  die 0.3–0.5 mm. Zero side contact, insensitive to die thickness, but it cannot pick
  from tape and needs a channel under every resting position. The rail gap is kept open
  so the fallback remains possible.

**Storage carrier: wafer trays with jaw slots (Fig. 4 shows one pocket row; rev. 2.6 — one 100 mm wafer ≈ 112 dies = one tray of 8 × 14 pockets, 132 × 106 mm; the die returns to its own pocket after test and the map carries the result).** Standard waffle packs have closed
pocket floors and pocket walls hard against the die ends, so they are replaced by a
machined (PEEK/Delrin) or SLA-printed **wafer tray** whose pockets have: two backside
**ledges** under the die's facet-edge strips, a 12.0 × 6.8 mm cavity that retains the die
by its corners to ±1.0 mm in X (inside the jaws' ±1.9 mm capture) and ±0.4 mm in Y,
3.6 mm **nose slots** in both end walls (a through channel along each column at the 16 mm pitch; floor 0.85 mm below the nose bottoms), lead-in
chamfers, and a lid for transport. Pockets sit 8 columns × 14 rows (16 mm pitch along
die X, 7.5 mm along Y), so one tray is ≈ 132 × 106 mm and holds one 4″ wafer; trays carry
a DataMatrix ID and pocket (row, column) mirrors the wafer map. *Rev. 2.7: the tray
supersedes the 14-pocket "stick" used in the figures and in the text below — read
"stick" as "tray" wherever it appears; the geometry of record is
[`cad/tray`](../cad/tray/README.md).* Trays are filled from the diced wafer on tape at the
**tape-to-tray sorting station** (§6b), which uses the same gripper — the one bare-die
handling step outside the tester.

**Transfer axes: bench-level 3-axis Cartesian (rev. 2.5; supersedes the SCARA choice).**
The gripper must enter a ~13 mm wide corridor under the objective, horizontally along
die X, with fiber arms occupying ±Y. That is a straight-line task, and the machine for it
is a linear axis: an X axis along the exchange direction at bench level, carrying a
short Z and a low horizontal gripper arm; a Y axis (or a stage under the sticks) to
index pockets; no θ — the jaw axis stays parallel to die X at every station. The
stages never enter the microscope or fiber volumes and the swept volume is a box that
can be drawn on the table and interlocked.

| Option | Verdict |
|---|---|
| **Bench-level 3-axis Cartesian** from motorized linear stages; rev. 2.11 sizes it to what the handling needs (±0.15 mm at the nest, ±0.3 mm at the tray, ±0.05 mm in Z, every position approached from one side) and selects three **MISUMI LX2005CG-B1-T2042** actuators (X L 300 / 236.5 mm stroke, Y L 200, Z L 100; lead 5 for speed, ±5 µm repeatability, 27 N·m moment rating on the X table; `docs/bom_month1.md` A1) over Velmex / Zaber / Thorlabs stages | **Selected.** Straight-line entry under the objective, predictable swept volume, no θ. The die is placed by hard references (stop pads, pocket walls), so the axes need repeatability, stiffness under the cantilevered arm and a power-off hold on Z, not µm accuracy. The prototype axes are the production kinematics; a second tray position needs a longer X (LX26/30 class). |
| 4-axis SCARA (Epson T3/T6 class) | Only with an offset gripper bar: the vertical quill must land at the die's X end, ~15 mm from center, where a Ø30–35 mm objective barrel is. With the bar it does nothing a linear axis cannot. |
| Articulated desktop arm (Dobot MG400 class) | **Rejected for the tester.** J2/J3 are pitch joints in a vertical plane (parallelogram wrist): the forearm approaches from above and behind, into the microscope column's volume, and its swept volume near the nest is an arc. Acceptable only for a bench-only cycling rig with no microscope. |
| Overhead gantry spanning the cell | Rejected for the tester (bridge lives where the column and fiber stacks are); right for the sorting station (Fig. 1), where nothing is above the wafer. |
| 6-axis articulated arm (Meca500, UR3e) | Rejected: unused DOF, slower, costlier, harder safety case. |
| Dedicated X-Z shuttle + indexing deck | This *is* the selected option in its minimal form; the difference is only whether Y is a third axis or a stage under the sticks. |

**Why one gripper everywhere — and the honest "why not":**

| For | Against (all testable in the same sorter trial) |
|---|---|
| One tool, one contact mode, one set of trials, one spare-parts list. | It is side contact ~1.5 mm from a facet corner; the tongue has zero side contact. |
| X and θ defined mechanically while held; vision corrects mostly Y. | Jaw step must stay below the top surface → Z known to ~±50 µm at every grip; die-thickness spec becomes mandatory. |
| Sticks and nest need only end clearance — no channels, no tunnels. | Heavily chipped or non-square diced end faces degrade θ definition and could cock the die in the jaws. |
| The tape step forces this gripper into the system anyway. | Jaw insert wear changes the 0.10 mm top gap → periodic gauge check. |

**Pickup alternatives considered and ranked below the edge gripper:**

| Method | Assessment |
|---|---|
| **Backside vacuum tongue** | Kept as the documented fallback for nest/stick handling (see above). Cannot pick from tape. |
| **Bernoulli non-contact top gripper** | Works with standard waffle packs and never touches the die, but blows air across exposed waveguides and facet edges (particle transport), has weak lateral constraint (needs end-face stops), and the body overhangs the facets. |
| Top vacuum pads in the 1-mm end zones | **Rejected.** A 0.6 mm pad in a 1 mm strip needs ±0.2 mm die-relative placement while pocket slop alone is ±0.25 mm; one miss puts a pad on a waveguide. |
| Top-and-bottom sandwich clamp at the end zones | **Rejected.** Still touches the top surface and adds nothing over end-face gripping. |
| Electrostatic top chuck | Rejected: unpredictable on pyroelectric LN. |

**Layout and operation.** X actuator at −X of the nest beside the input fiber stage
(centre-line Y −140) on its own riser bar, decoupled from the nest base plate, so its
motion never enters the metrology loop; its 52 mm band lies beside the tray's Y sweep, so
nothing passes under it. The Z actuator stands on an angle bracket on the X table with
its brake motor up; one 25 mm square bar runs from the Z table along +Y to the gripper.
The tray rides on the Y actuator under the arm, columns along X from die X −95 to −207,
outside both fiber corridors (`cad/station/README.md`). The axes move **only while fibers are retracted** and is parked
during every measurement, so pipelining is not needed in the long-test regime; in the
screening regime the incoming die is pre-staged in a second gripper before the fibers
retract, making the swap itself ~5 s and the full exchange 15–25 s including vision
registration and correction. Operator role: remove stick lids, load the hotel, press
start.

### 6b. From dicing tape to sticks

Dies arrive **on dicing tape on a film frame, with kerf-width streets (tens of µm)**
between them, facets facing facets along the optical axis. Neither the tongue nor any
backside tool can pick from tape: the backside is glued down, there is no channel, and
lifting one die with kerf-width gaps tilts it into a neighbor's facet. The standard
tape pick — ejector needles below, vacuum collet on top — is excluded by the no-top-
contact rule. Tape release is therefore a **separate process step, done once, off the
tester**, producing loaded sticks.

**Release recipe (standard die-attach practice, adapted to end-face gripping):**

1. **UV-release dicing tape.** Confirm the vendor's tape; if UV-release (Lintec Adwill
   D-series, Nitto UV types), a 365 nm cure of a few minutes drops adhesion ~10×.
   Specify UV tape for future lots. Plain acrylic tape still works with more peel
   force. **No thermal-release tape** — LN is pyroelectric and heating charges the dies.
2. **Tape expansion.** A film-frame expander stretches the tape radially and locks it in
   a grip ring. At 10 mm pitch, ~10 % expansion opens the streets to ~1 mm — no die can
   touch a neighbor while lifted, and the stretch pre-breaks adhesion at the edges.
3. **Ejector from below.** A vacuum anvil holds the tape down around the target die
   while pins push up through the tape and peel it from the backside, leaving the die
   on the pin tips ~1 mm above its neighbors. Four rounded pins under the corners of
   the 1 mm end zones (or a needle-less dome ejector). Backside contact only.
4. **Grip by the non-optical end faces.** A parallel micro-gripper with thin PEEK/Vespel
   jaws takes the raised die by its two X-end faces entirely above the neighbors'
   plane. A **stepped jaw** whose top lies below the die's top surface makes contact
   with the waveguides geometrically impossible. Force 0.2–0.5 N (≈ 0.4 MPa on a
   0.3 × 4 mm patch — negligible for LN). The gripper lifts clear and lowers the die
   onto the rails of a stick pocket; pockets get end-face jaw clearance slots.
5. **Wafer map → stick map.** Every die on tape has a known grid position and the same
   orientation, so the sorting step yields die IDs and orientation for free: the 180°
   ambiguity disappears and the robot's θ axis is no longer needed for it.

**Where it lives:** a **bench tape-to-stick sorting station** — film-frame holder with
expander, UV lamp, ejector, camera, and a small XY carrying the edge-grip head;
semi-automatic is sufficient at hundreds of dies. Alternatives: buy a small commercial
die sorter and fit an edge-grip head, or have the dicing vendor deliver into sticks or
Gel-Pak using an edge-grip/Bernoulli head with **no top collet** (some
photonics-oriented services offer this). The film frame is **not** integrated into the
tester: a 200/300 mm frame plus ejector is a large mechanism unrelated to optical
testing, and decoupling keeps the tester's hotel simple.

**Interactive 3-D model.** `docs/die_handling_3d.html` is a self-contained three.js
page (open it in a browser) with four scenes — nest exchange, pick from tape, place into
stick, sorting-station layout — each with a step scrubber, the two undetermined
parameters as sliders (objective working distance, street width after expansion) and
live clearance readouts that turn red on interference.

**Station layout and pick geometry (Figs. 1–3).**

Fig. 1 — sorting station layout

The wafer table (X–Y ±70 mm, θ ±3°) moves the expanded frame so that the target die
sits over a **fixed pick point**: ejector and tape-vacuum anvil below the tape,
down-looking camera above, gripper head on a small X–Y–Z gantry that also reaches the
four-stick deck (pass / fail / regrade / spare). A gantry is right here, unlike at the
tester, because nothing lives above the wafer. UV cure is done offline before mounting.

Fig. 2 — pick moment: ejector and jaws

At the pick moment the anvil vacuum holds the tape, four Ø0.5 mm pins under the 1-mm
end zones raise the die ~1 mm, the tape peels and tents, and the jaws descend beside
the end faces **above the neighbours' plane** — with ~1 mm streets after expansion no
tilt of the lifted die can reach a neighbour's facet.

Fig. 3 — contact zones and stepped jaw

**Decision (rev. 2.4): the same end-face gripper is used everywhere** — tape pick, nest
exchange, binning (rationale and the "why not" list in §6a). The sorter trial
(≥ 300 picks with facet, top-surface and end-face inspection every 50) is the gate for
the tester build, not for the tool choice; if the trial fails on end-face damage or
θ repeatability, the documented tongue fallback takes over the nest/stick handling and
the sorter falls back to a Bernoulli head.

**For future layouts:** 300–500 µm streets would make tape release markedly easier and
safer; at 10 × 6 mm dies the area cost is a few percent.

**Why via S3:** the single highest-risk item is now: does end-face gripping plus
backside support with vision registration deliver ±10–25 µm / ±0.05° at the fibers over
hundreds of cycles with **zero** top-surface or facet damage? That is answered fastest
and cheapest by building **one rail-pair nest, one gripper on a hand-positioned or cheap
stage, and one stick** (S3 hardware minimum) — the same gripper the sorting station
needs — cycling dies through a few hundred times, and inspecting. Everything built for
that test (nest, gripper, stick geometry, vision registration,
fiber choreography, orchestration software) is carried unchanged into S1; the longer axes
and hotel are then a procurement-and-integration project around a proven core, not a
gamble. If the trials instead show any bare-die robot handling is untenable, the same
data redirects the build to S2 with minimal loss.

**Throughput picture (full-characterization regime, `T_measure` ≈ 60 min/die):**
utilization is the whole game — S1 at ~90 % utilization tests ~21 dies/day vs ~7/day
for any attended single-die flow; 300 dies ≈ 2 weeks unattended vs ~6+ weeks attended.
**(Screening regime, `T_measure` ≈ 3 min/die):** with pipelined exchange (~20 s) and
verification-grade first light (~10–20 s), S1 sustains ~12–15 dies/hour, ~300 dies in
one lights-out day.

---

## 7. What is retained from the current machine, and what is not

| Current element | Disposition in redesign |
|---|---|
| Per-waveguide automation software (first light, raster/Z-scan, full-chip stepping, transfer-function capture) | **Retained** — becomes the measurement engine inside the campaign state machine. |
| Fiber coarse XYZ stepper stacks (DS102) | **Retained as components** of the new fiber aligners, augmented with piezo fine stages. |
| Camera + OpenCV pose/verify methods | **Retained**, re-pointed at the fixed nest. |
| Center sample stage (X + θ, single-die chuck) | **Not retained** as the sample platform. Its X axis has no role once transfer is robotic; X and θ are registered mechanically at the nest (push-to-stop, §3), Y is absorbed by the fiber stages. |
| Manual die placement / tweezer workflow | **Removed from the tester.** The one remaining manual touch per die is loading storage sticks at a bench, gripping the non-optical end faces. |
| Open-frame bench layout | **Replaced** by an enclosed, interlocked, ESD-managed cell (required once a robot moves near fibers). |

---

## 8. Measurements and decisions required before detailed design

1. **Fiber/chuck 3-D envelope** (tip-to-first-bulky-feature, holder W×H, safe retract,
   full swept volume during alignment) → rail recess, robot keep-out, parking
   positions.
2. **Die contact constraints — partly settled:** no top-side contact anywhere (air-clad
   waveguides, rev. 2.2) and no facet contact. Still to confirm: backside condition
   (bare substrate vs metallization/handle wafer, allowed vacuum stress, contamination
   class) → rail materials and vacuum level; end-face condition → jaw insert material.
3. **Die dimensional data** (thickness ± tol — this sets the stepped jaw's 0.10 mm top
   gap and the support heights; dicing size and squareness tol; end-face and facet edge
   condition as-received) → jaw geometry, pocket dimensions, vision-registration range,
   θ budget check.
4. **Nest seating trials** (the S3-minimum prototype): repeatability over ≥ 300
   seatings, facet-edge inspection every 50, vacuum-seat detection ROC → the go/no-go
   data for S1 vs S2.
5. **First-light capture range in practice** (from existing logs: raster window sizes
   that converge reliably) → confirms the ±10–25 µm / ±0.05° presentation budget.
6. **Incoming format — settled: diced wafer on tape on a film frame.** To determine:
   tape type (UV-release or not), frame size, actual street width after dicing, die
   thickness on tape → sorting-station specification (§6b) and whether the vendor can
   deliver into sticks with an edge-grip head instead.
9. **Vision registration accuracy at the nest:** camera µm/pixel (already measured by
   the `SoftwareFence` calibration), facet-edge and fiducial detection repeatability →
   confirms X/Y/θ can be zeroed to inside the presentation budget without side datums.
10. **Objective working distance and barrel diameter** → whether the fixed vision column
   clears the jaw bodies (~13 mm corridor, Fig. 4) or must retract.
7. **Test-plan regimes:** expected mix of full characterization vs screening per
   campaign → pipelining priority and hotel sizing.
8. **Throughput accounting on the current tester** (operator minutes and interventions
   per die today) → the baseline the business case is measured against.

## 9. Risks and open questions

- Vision-only in-plane registration: facet-edge detection must be robust to facet
  quality variation and illumination; mechanical X/θ on the end faces is the documented
  add-on if it is not (§3).
- Jaw Z reference: the 0.10 mm top gap of the stepped jaw relies on die thickness
  (±50 µm spec) and on known support heights (pins, rails, ledges) across sticks from
  different batches; a gauge die and a periodic jaw-wear check are part of the design.
- Rail recess (~1 mm inboard of the facet) versus the true fiber/clamp envelope — a
  fiber crash now meets a rail instead of empty space; the software fence and rail
  material (no harder than the fiber ferrule) must reflect that.
- Tape release at kerf-width streets: without expansion, a lifted die can tilt into a
  neighbor's facet; the expander and UV cure are therefore mandatory, not optional, in
  the sorting recipe (§6b). Verify expansion ratio achievable with the vendor's tape.
- Edge-gripper reliability on diced end faces (chipping, non-parallel faces, jaw insert
  wear): the sorter trial is the gate; failure redirects to the tongue fallback at the
  nest and a Bernoulli head at the sorter.
- Correction-stage motion per die adds ~5–10 s and a moving element under the nest;
  its stiffness and settling must be characterized so nothing sample-side drifts
  during a measurement.
- Error-recovery completeness: the value of S1 is unattended running; every credible
  fault (mis-pick, double die, cocked seat, no first light, power loss mid-run) needs a
  scripted, tested recovery path — this is software scope, and it is large.
- If any future measurement requires temperature control at the die, revisit S4's
  trigger condition before committing the nest design.

---

## Appendix A — The current bench as built, and what it implies

Reference photo: `docs/images/current_setup.jpg`.

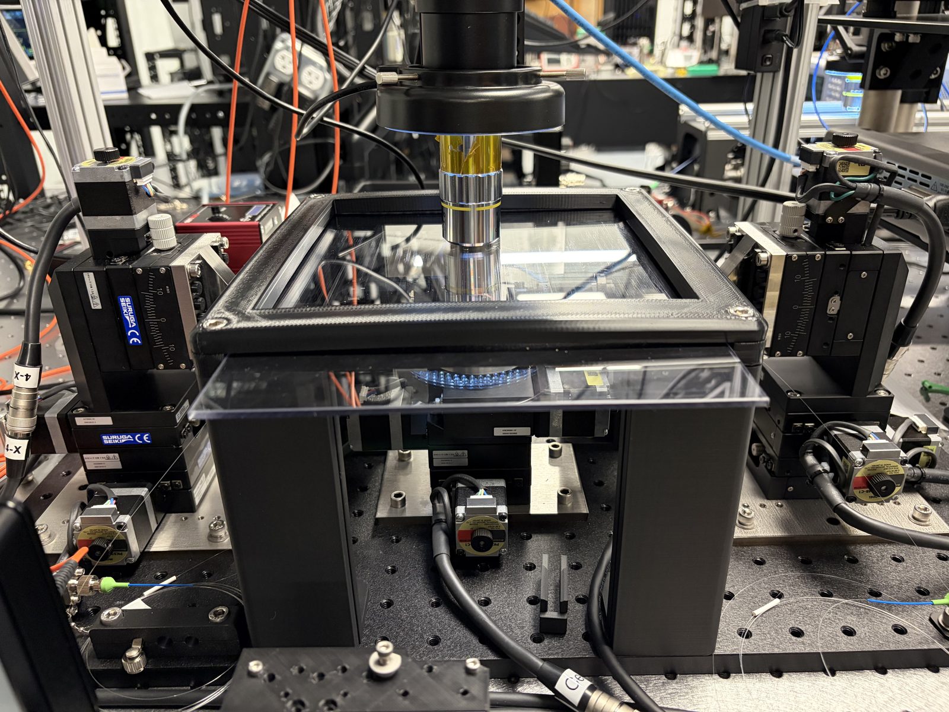
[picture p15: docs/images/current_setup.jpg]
Current manual die-tester setup


| Observation | Design consequence |
|---|---|
| Chip stage (X + θ stack) stands on a tall tower inside a small 3D-printed enclosure with a glass top window and a clear acrylic front panel; a ring illuminator sits inside. | Still-air/dust control is an existing requirement, currently met at die scale. The redesign scales the enclosure to the whole cell (§6) rather than boxing the nest. The tall tower goes: the nest sits low on the common base plate for stiffness and to free vertical room for the exchange tool. |
| High-magnification objective on a vertical microscope column, pointing down through the top window, a short working distance above the die. | The overhead camera is the natural verify camera and is retained, but it occupies the +Z approach. Die exchange must enter along ±X beneath it, or the column must retract; objective-to-die gap becomes an interlock (§6). Working distance of the current objective is a required measurement (§8). |
| Two Suruga Seiki motorized XYZ stacks (Oriental Motor steppers, manual micrometer verniers) mounted outside the enclosure; fibers on long, thin cantilevered holder arms with V-groove clamps near the tip, passing through slots in the ±Y enclosure walls. | The arm, not the fiber, is the keep-out body: nest pedestal recess and any ±Y structure are sized from arm/clamp dimensions and the alignment sweep. The slotted walls also show today's approach corridor is already tightly constrained — in the redesign the ±Y corridors stay fully open inside one enclosure. The stacks are retained as coarse stages under added piezo fine stages; the arms should be shortened and stiffened once the enclosure no longer forces a long reach. |
| Fiber pigtails (FC/APC) and stage cables lying loose on the breadboard; blue/orange patch cables overhead; 80/20 framing close around the table. | Fiber and cable management becomes a design deliverable (captive routing, strain relief, no fiber in any robot volume). The redesigned cell should be a self-contained module on its own base plate (~600 × 500 mm footprint class) so it can be placed and, if needed, relocated as one unit within the existing frame. |
| Everything is bolted individually to the optical table (stages, tower, microscope). | Replace with a single stiff base plate carrying nest, both fiber aligners and the vision column, so thermal and structural drift is common-mode across the metrology loop; the table then only isolates vibration. |

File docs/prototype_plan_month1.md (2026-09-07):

# Month‑1 Prototype Plan — Robotic Die Exchange on the Existing Tester

**Goal of the month:** prove, with real hardware and real dies, that a 10 × 6 × 0.5 mm
air‑clad TFLN die can be picked by its end faces, carried, set on the vision‑registered
nest, coupled by the existing auto‑alignment, and returned to its wafer-tray pocket — **hundreds of
times, without damage, with nobody touching the die**. End the month with an
unattended N‑die loop running on the current tester.

**What the month deliberately does not include:** the enclosure, a second tray position, the
production‑length axes, the X‑Y‑θ correction stage, automated tape pick, error‑recovery
software beyond "stop and alarm". Those are Month 2–3 and they all depend on Month 1's
answer.

---

## 1. What to prototype first, and why

The whole architecture (concept study §3, §6a) rests on one unproven claim: *a bare
photonic die can be gripped repeatedly by the middle of its non‑optical end faces and
set down on a backside chuck and pushed onto two end‑face stop pads, within ±0.3 mm / ±1°, with zero top‑surface or facet damage.*
If that is true, the rest is procurement and integration. If it is false, the design
redirects to the backside tongue and everything downstream changes. So:

1. **First:** the **gripper + nest + tray pocket** contact system, cycled by hand on a manual
   stage before any robot exists. This answers the damage question in week 2 regardless
   of robot lead time.
2. **Second:** the same gripper on the 3‑axis Cartesian doing **A → B → A**
   (tray → nest → tray) for hundreds of cycles with placement statistics from the
   camera.
3. **Third:** the nest at the real optical station, fibers interlocked, the existing
   `run_all_waveguides` measuring dies the robot exchanged. This is the demo.
4. **Not yet:** picking from dicing tape. It needs the expander, UV cure and ejector;
   in Month 1 we only gather the facts (tape type, street width) and do one manual
   needle‑eject experiment on a scrap wafer segment.

"Pick from point A to point B" is exactly the right first robot task — but A and B
must be **tray pocket and nest**, not the tape.

---

## 2. Parts that work, with lead times

The orderable list with exact part numbers, vendors, checked prices and the outsourcing decision is in **`bom_month1.md`**; this table is the summary.

Prices are indicative US list prices; lead times are typical for in‑stock items.
**Order the robot, gripper, and machined parts on day 1.**

| Item | Choice | Alternative | Approx. cost | Lead time |
|---|---|---|---|---|
| **Transfer axes** | Bench‑level 3‑axis Cartesian from three MISUMI LX2005CG‑B1‑T2042 actuators (X L 300, Y L 200, Z L 100; lead 5, cover, low‑particulate grease) with Oriental Motor AZM46 steppers (brake on Z) — gripper arm enters under the objective along die X; no θ (`docs/bom_month1.md` A1) | Velmex BiSlide if MISUMI slips; Dobot MG400 for the bench‑only rig only (not at the tester: articulated arm approaches from above/behind into the microscope volume) | ~$3–3.5 k | 1 week (MISUMI 3–5 days) |
| **Production transfer axes (Month 2)** | Longer versions of the same Cartesian (X 300, Y 300, Z 60 mm), same software | SCARA only with an offset gripper bar (vertical quill lands where the objective barrel is) | ~$10–14 k | 3–6 weeks |
| **Gripper actuator** | SMC MHZ2‑6D pneumatic parallel gripper (4 mm total stroke) + precision regulator (SMC IR1000) + 5/2 valve (SY3120) + D‑M9 position sensors | Electric: Schunk EGP 25 or Zimmer GEP2010 (no air needed) | ~$300 pneumatic / ~$1.5–2 k electric | in stock / 2–4 weeks |
| **Jaw fingers** | Custom aluminum fingers with PEEK or Vespel SP‑1 inserts; stepped nose per Fig. 3; **one finger on a flexure or pivot with a 0.3 N spring stop** so grip force is set by the spring, not by air pressure | Bare PEEK fingers (no compliance) for the very first trial | ~$300–600 | 5–7 days (Protolabs/Xometry) or in‑house |
| **Nest** (chip stage) | Three parts (`cad/nest`): Ni‑plated **copper vacuum chuck** with a lapped 9 × 5 mm pad, 6 vacuum holes and a neck to a 15 × 15 mm TEC; **Semitron ESd 480 cage** with two +X stop pads (X and yaw by push‑to‑stop), an X guard and four corner Y guards; **6061 T‑riser** / heat sink with a 10 mm neck between the fiber holders, on the **die stage** (MISUMI RMPG40W‑N motorized rotary on a Suruga KXC04015‑C X stage, on a KB1X1 base; NanoMax stages on 25 mm risers) that steps the die from device to device | Cage without the TEC (blank copper block) for the first contact trials; the existing Suruga centre stage as the X stage if the KXC04015‑C is late | ~$600–1,000 + TEC | 1 week |
| **Vacuum** | Lab house vacuum or KNF N86 micro pump; SMC ZSE30A digital vacuum switch (seat sensing); 3/2 valve | — | ~$400 | in stock |
| **Wafer trays** (replace the sticks) | SLA print (Formlabs Rigid 10K or Protolabs Accura): 8 × 14 = 112 pockets (one 4″ wafer), cavity 12.0 × 6.8 mm with corner retention, 3.6 mm nose slots, ledges, lid; see `cad/tray/README.md` | Machined PEEK later | ~$120–250 per tray | 2–4 days |
| **I/O** | Stage‑controller digital I/O (Zaber X‑MCC / Thorlabs KDC101 triggers) or the existing NI USB‑6363 lines with a 24 V isolator module | Arduino | ~$80 | — |
| **Vision** | Existing overhead microscope camera + `ChipAlignmentController` template/edge methods for pose at the nest; a USB microscope for the bench rig | — | ~$100 | in stock |
| **Test dies** | (a) 50 diced silicon blanks 10 × 6 × 0.5 mm for cycling; (b) 20 diced LN blanks for contact realism; (c) 10–20 **scrap real TFLN dies** for damage tests | — | ~$300–800 (dicing service) | 1 week |
| **ESD** | Bench ionizer (Simco‑Ion Aerostat PC or similar), grounded fixtures, dissipative jaw inserts | — | ~$600–900 | in stock |
| **Manual rig** | Thorlabs manual XYZ stage (from lab stock) + adapter plate to carry the gripper over nest and tray | — | ~$0–300 | in stock |

**Not needed in Month 1:** X‑Y‑θ correction stage (the nest registers X and yaw mechanically; the die stage under it only steps devices and carries the once‑set RPG38 yaw trim),
film‑frame expander, UV box, enclosure, safety light curtain (bench run attended).

---

## 3. Week‑by‑week

Two people: one mechanical/integration (M), one software/test (S). Dates are working
days.
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

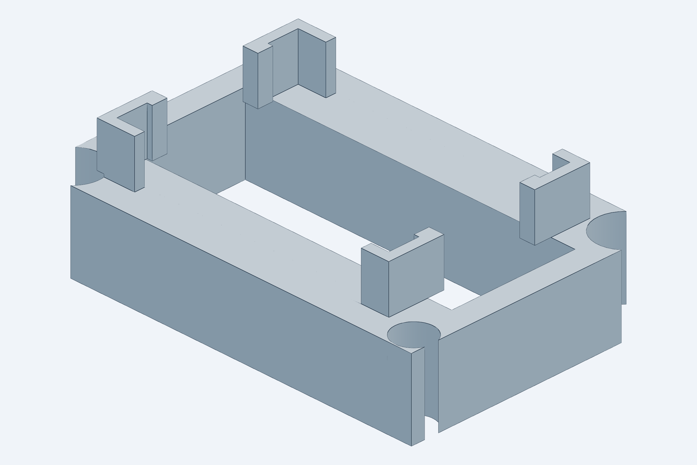
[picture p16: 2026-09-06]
cad/nest/renders/nest_cage_iso.png

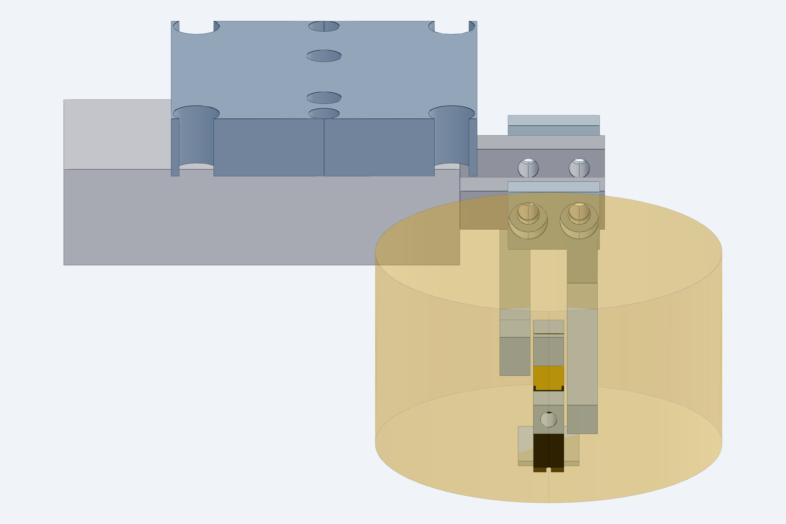
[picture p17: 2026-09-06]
cad/gripper/renders/gripper_h_side.png

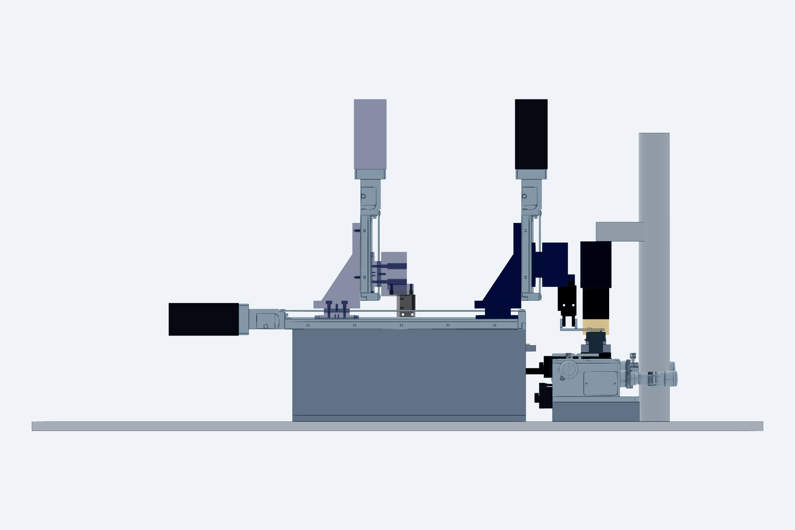
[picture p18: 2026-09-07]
cad/station/renders/station_front.png

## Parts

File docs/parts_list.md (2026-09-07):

# Parts list: buy, machine, print

**Status:** rev. 1 (2026-09-07). One page that sorts every part of the prototype by how it is obtained.
Prices, vendors and lead times are in [`bom_month1.md`](bom_month1.md); print settings, orientations and
finishing steps are in [`print_list.md`](print_list.md); the CAD files are under `cad/*/STEP` and `cad/*/STL`.
"Prototype" is the first build on the bench rig and the tester; "final" is what replaces a printed part after
the hand-cycling and sequence trials.

## 1. Purchase

| Group | Part | Qty | Note |
|---|---|---|---|
| Transport axes | MISUMI LX2005CG-B1-T2042-300 / -200 / -100 (X / Y / Z) | 1 each | high grade, 1 long block, lead 5, cover, low-particulate grease, T2042 plate |
| | Oriental Motor AZM46AK (X, Y), AZM46MK with brake (Z) | 2 + 1 | αSTEP AZ, 42 mm, absolute encoder |
| | Oriental Motor AZD-KD drivers (or one AZD-KR2D-class multi-axis) + cable sets | 3 | 24/48 V DC, RS-485 Modbus |
| | 48 V supply, Mean Well LRS-150-48 class | 1 | |
| | slit clamp couplings Ø4 (screw) × Ø6 (motor), MISUMI MCSLC20 class | 3 | not included with the actuator |
| | LX20 sensor sets: DG20X flag kit + 3 × GXL-8F per axis | 3 | home / limit backstop |
| Die stage | Suruga KXC04015-C X stage | 1 | runs on the existing DS102 #3 |
| | MISUMI RMPG40W-N motorized rotary | 1 | DS102 θ axis |
| | Thorlabs KB1X1 kinematic base | 1 | |
| | micro-TEC 15 × 15 × 2.5 (Laird OptoTEC OT08 class or TE Technology TE-63-1.0-1.3) | 1 (+1) | |
| | 10 kΩ glass-bead thermistor | 2 | |
| Gripper and pneumatics | SMC MHZ2-6D-M9N with 2 × D-M9N switches | 2 | one spare |
| | SMC SY3120-5LZ-M5 (gripper valve) | 2 | one spare |
| | SMC VQ110-5L-M5 (chuck vacuum, blow-off) | 2 | |
| | SMC AS1201F-M3-04 class meter-out speed controllers | 2 | ≤ 10 mm/s finger speed |
| | SMC IR1000-01 precision regulator (+ IR1000 class for the few-kPa blow-off) | 1 + 1 | |
| | SMC ZSE30A-01-N-L vacuum switch | 1 | seat sensing |
| | KQ2H04-M5 ×10, KQ2H04-01S ×4, KQ2T04-00A ×4, TU0425 Ø4 tubing 20 m | — | |
| | Mean Well LRS-50-24, 2 × 24 V relay/isolator modules, 24→5 V optocoupler inputs | 1 set | valves and switches to the NI USB-6363 |
| | die-present sensor (blade-deflection photo-microsensor or inductive) | 1 | chosen after the rig trials |
| Consumables and hardware | 0.005″ C1095 feeler-gauge stock (flexure blades) | 1 pack | 6 blades |
| | Loctite EA 9460 (blade-to-block bond) | 1 | |
| | gauge die 10.000 × 6 × 0.500, steel or ceramic | 1 | ground; sets the switches and the 0.10 mm top gap |
| | stainless SHCS: M2 × 5/6, M3 × 8/16, M4 × 10/16/40, M6 × 16/50; Ø3 × 8/10 and Ø4 × 8 dowel pins; 0.05 mm shim stock | — | per `print_list.md` |
| | heat-set inserts M3 / M4 (optional, for joints undone often) | — | |
| Stock for machining | C101 copper (chuck), Semitron ESd 480 rod/sheet (cage, tip blocks), 6061 plate and bar (risers, brackets, adapters) | — | Boedeker / Professional Plastics; McMaster |
| Printing | Bambu PPA-CF filament, hardened 0.4 nozzle | 2 spools | ~2 kg of parts incl. the risers |
| Bench rig | Thorlabs PT3 (if not in stock), MB1218 breadboard, AP90 / RS2P / TR75 | 1 set | hand-cycling rig |
| | AWS GEMINI-20 0.001 g scale | 1 | jaw force check |
| | Ideal-tek 2ACFR.SA.1 tweezers with A2ACF carbon-fiber tips | 3 | the only approved hand tool |
| | Simco-Ion Aerostat PC2 ionizer | 1 | before real dies are cycled |
| | Dino-Lite AM7915MZT (optional) | 0–1 | if the microscope cannot serve the rig |
| | compressor + SMC AW20 filter-regulator (if no house air); KNF N86 KN.18 pump (if no house vacuum) | 0–1 each | |
| Test dies | Si 100 mm wafers, 500 µm, diced 10 × 6 (APD) | 2 wafers | ~200 blanks |
| | LN wafer, 0.5 mm, diced 10 × 6 | 1 wafer | Gate 1 |

## 2. Machine

| Part | File | Material | Process | When |
|---|---|---|---|---|
| Vacuum chuck | `cad/nest/STEP/nest_chuck_copper.step` | C101 copper, Ni plated | CNC, pad lapped in-house ≤ 3 µm | now (+1 spare) |
| Cage with stop pads and guards | `cad/nest/STEP/nest_cage_semitron.step` | Semitron ESd 480 | CNC | now |
| Far and near tip blocks | `cad/gripper/STEP/far_tip_block_semitron.step`, `near_tip_block_semitron.step` | Semitron ESd 480 | micro CNC, crown R 30 | now, 3 of each |
| Gauge die | — | steel or ceramic | grind | now |
| NanoMax riser plates ×2 | `cad/station/STEP/nanomax_riser_6061.step` | 6061 plate 112 × 112 × 25 | mill, drill | with the chuck (metrology loop) |
| Nest T-riser | `cad/nest/STEP/nest_riser_6061.step` | 6061 | CNC | final (TEC heat path) |
| KB1X1 → KXC adapter, KXC → rotary spacer | `cad/nest/STEP/nest_adapter_kb_kxc.step`, `nest_spacer_kxc_rot.step` | 6061 | waterjet + tap / mill | final (metrology loop) |
| Gripper bracket, far arm, near arm | `cad/gripper/STEP/bracket_6061.step`, `far_arm_6061.step`, `near_arm_6061.step` | 6061-T6, arms hard anodised | CNC | final, after the rig trials |
| Tower bracket | `cad/station/STEP/tower_bracket_6061.step` | 6061 | mill from a 60 × 60 × 110 block | final |
| Arm | `cad/station/STEP/arm_6061.step` | 6061 (stock 25 sq bar + machined block acceptable) | mill | final |
| X and Y riser bars | `cad/station/STEP/x_axis_riser_6061.step`, `y_axis_riser_6061.step` | 6061 bar (or 80/20 40 × 120 profile with a tapped top plate) | saw, face, drill, tap | final |
| Tray deck | `cad/station/STEP/tray_deck_6061.step` | 6061 plate | mill | final, or keep the print if the pocket floor measures flat |

## 3. Print (Bambu H2C, PPA-CF)

| Part | File | Purpose | Notes |
|---|---|---|---|
| Wafer tray | `cad/tray/STL/wafer_tray_8x14.stl` | prototype **and** likely final | ×4; ledge plane flat within 0.1 mm; check surface resistance |
| Gripper bracket, far arm, near arm | `cad/gripper/STL/bracket_6061.stl`, `far_arm_6061.stl`, `near_arm_6061.stl` | prototype (rig and tester) | blade slot printed 0.5 wide and potted |
| Tower bracket | `cad/station/STL/tower_bracket_6061.stl` | prototype | |
| Arm | `cad/station/STL/arm_6061.stl` | prototype | one piece, no supports on its side |
| Tray deck | `cad/station/STL/tray_deck_6061.stl` | prototype, possibly final | |
| X riser bar | `cad/station/STL/x_axis_riser_6061.stl` | prototype | 300 mm, on its side, ~0.7 kg |
| Y riser bar | `cad/station/STL/y_axis_riser_6061.stl` | prototype | |
| Nest T-riser, KB adapter, spacer | `cad/nest/STL/nest_riser_6061.stl`, `nest_adapter_kb_kxc.stl`, `nest_spacer_kxc_rot.stl` | fit check and cold trials only | metrology loop: aluminium for anything measured |
| Cage, coarse version | `cad/nest/STL/nest_cage_semitron.stl` | sequence rehearsal on silicon blanks only | never meets a TFLN die |
| NanoMax riser plates | `cad/station/STL/nanomax_riser_6061.stl` | fit check only | |

Not printed: the tip blocks (feature size and abrasion), the chuck (vacuum, flatness, heat), the blade (feeler
stock), the gauge die.

## 4. Existing on the bench, reused

Two Thorlabs NanoMax 300 (MAX313D/M) with fiber holders, the microscope with its column, the Suruga DS102
controller #3 (die-stage X and θ), the NI USB-6363, the optical table.

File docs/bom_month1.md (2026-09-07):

# Month‑1 Bill of Materials — Robotic Die Exchange Prototype

Companion to `prototype_plan_month1.md`. Every line is an orderable part or a quote
request to a named vendor. Prices are US list/street prices checked in September 2026
unless marked **quote**; lead times are for in‑stock items. Total for everything to
order now: **≈ $8–10 k with the MISUMI LX20 axes** (≈ $5–7 k if the lab already has a manual XYZ
stage, house vacuum and compressed air; ≈ $10–12 k with Velmex, ≈ $13–16 k with Zaber/Thorlabs axes);
the nest stages and the transfer axes are the largest items and are also the production kinematics.

**Check before ordering (day 0):**
1. Is there compressed air (or nitrogen at ≥ 0.3 MPa) at the bench? If yes, skip A6.
2. Is there house vacuum at the bench? If yes, skip A7.
3. Is a Thorlabs PT3 (or any 25 mm manual XYZ) in lab stock? If yes, skip B1.
4. Ask the dicing vendor today: tape type on the current lot, post‑dicing street width,
   frame size, die thickness distribution.

---

## A. Order on day 1 (lead time or critical path)

| # | Item | Exact part | Vendor | Unit price | Qty | Lead | Why this one |
|---|---|---|---|---|---|---|---|
| A1 | Transfer axes (prototype **and** production kinematics) | **Bench‑level 3‑axis Cartesian from three MISUMI LX20 single‑axis actuators**, sized to what the handling needs (±0.15 mm at the nest, ±0.3 mm at the tray, ±0.05 mm in Z; the die is placed by hard references, every position approached from the same side): **LX2005CG‑B1‑T2042‑300** (X, 236.5 mm stroke, 209 used), **LX2005CG‑B1‑T2042‑200** (Y, 136.5 mm, 97.5 used), **LX2005CG‑B1‑T2042‑100** (Z, 36.5 mm, 20 used). High grade (±5 µm repeatability), one long block, **lead 5** (690 mm/s screw‑rated, ~200 mm/s with the motor below), **cover included and low‑particulate grease** (the Z axis hangs over the nest), motor adapter **T2042** (42 mm square stepping motors; the CAD files were downloaded with the A2040 servo plate, same casting and outline, so order with T2042). **Motors, stepper route (decided):** Oriental Motor αSTEP AZ series, closed‑loop with a battery‑free mechanical absolute encoder (no homing after power loss, no hunting at rest): **AZM46AK** ×2 (X, Y) and **AZM46MK** ×1 (Z, electromagnetic brake: a lead‑5 ball screw back‑drives under the 1.7 kg tower), three **AZD‑KD** drivers (24/48 V DC, built‑in positioning controller, RS‑485 Modbus from Python) or one multi‑axis AZD‑KR2D‑class driver, motor/encoder cable sets, a 48 V supply (Mean Well LRS‑150‑48 class). Couplings are not included with the plate: 3 × slit clamp coupling Ø4 (screw end) × Ø6 (AZM46 shaft), MISUMI MCSLC20 class. Home/limit by the LX20 sensor‑rail proximity set (DG20X flag kit + 3 × GXL‑8F) as a safety backstop for the absolute encoders. The servo route on A2040 (50 W □40 servos, ~2× the price for 250–500 mm/s) was considered and rejected: the lead‑5 screw already gives ~200 mm/s, i.e. ~1.3 s per 207 mm X move against alignment times of tens of seconds. The three MISUMI STEP files are placed in `cad/station` (`cad/vendor`, git‑ignored). **Fallbacks:** Velmex BiSlide MN10‑0100/0050 + VXC (~$4–5 k, 5 µm, 2–3 wk); FUYU FSL40 / igus drylin modules on a G‑code board (~$1 k, 20–50 µm, no moment ratings). | MISUMI USA (configurator, 3–5 days); Oriental Motor USA | actuators ~$550 + $500 + $460 (list, high grade; +$40 each for the G grease is included in the part number); AZM46 + AZD‑KD **quote** (~$600–750 per axis), couplings ~$40 each, sensor sets ~$100 per axis; ≈ **$3.5–4 k** for the three axes | 1 set | MISUMI 3–5 days (11 for F/N types); Oriental Motor in stock | The tool must enter a ~13 mm corridor under the objective horizontally along die X and never cross the fiber line. The X actuator lies beside the input NanoMax at Y −140 on one riser bar, its 52 mm band outside the tray's Y sweep, so nothing passes under it; the Z actuator stands on an angle bracket on the X table; the arm is one 25 mm bar along +Y. No θ axis. Same kinematics scale to the production cell (`cad/station/README.md`). |
| A1b | Bench‑only fallback robot (only if A1 lead time > 3 weeks) | **Dobot MG400** (articulated desktop arm: J2/J3 pitch in a vertical plane, parallelogram wrist, ±0.05 mm, 24 V DIO, TCP/IP) | RobotLAB $2,890; RobotShop; Dobot US | $2,890 | 0–1 | 1–2 wk | Fine for the tray → nest → tray cycling rig where there is no microscope. **Not for the tester**: its forearm approaches from above and behind, into the microscope column's volume, and it is not a horizontal‑plane SCARA. |
| A2 | Gripper actuator | **SMC MHZ2‑6D‑M9N** (ø6 parallel gripper, 4 mm total stroke, 0.15–0.7 MPa, with two D‑M9N solid‑state position switches) | SMC USA / Motion / Southern Controls / RS | ~$60–120 gripper; ~$40 per switch | 2 (one spare) | in stock | Its 3.3 N external force is irrelevant: the die load is set by the flexure jaw (see fingers). Two switches give "closed on die" vs "closed empty" = die‑present detection. Sensors and valves wire to the stage controllers' digital I/O (Zaber X‑MCC / Thorlabs KDC101 trigger lines) or to the NI USB‑6363 via a 24 V ↔ 5 V isolator module; confirm N/P polarity accordingly. |
| A3 | Jaw fingers + flexure | **Custom**: 2 aluminum 6061 fingers per Fig. 3 (stepped nose 0.35 mm, 0.6 mm set‑back, ≥ 13 mm long), one rigid, one carrying a spring‑steel flexure blade (k ≈ 3 N/mm) with a hard stop; jaw inserts machined from **Semitron ESd 480** (static‑dissipative PEEK) | Protolabs / Xometry CNC; Semitron from Boedeker or Professional Plastics (cut‑to‑size rod/sheet, in stock) | quote (~$300–600 incl. material) | 2 sets | 5–7 working days | Force = k × (δ + die tolerance) ⇒ 0.3 ± 0.08 N for ±25 µm dies, independent of air pressure. Semitron ESd 480 is the standard dissipative jaw material for bare‑die handling. |
| A4 | Test nest (chip stage, `cad/nest`) | **Custom, three parts**: (a) **copper chuck** C101, Ni‑plated — 9 × 5 mm pad island lapped flat ≤ 3 µm (75 % of the die backside on metal, 0.5 mm inboard of every edge), 6 × Ø0.5 vacuum holes into a plenum, Ø1.5 vacuum stub tube out of the −X face, Ø1 thermistor bore from +X, neck down to the TEC; (b) **Semitron ESd 480 cage frame** with four corner blocks: two +X stop pads (Y 0.6–1.2 / 4.8–5.4, face at X 10.000, contact band Z 0.05–0.30, tops 0.09 below the fiber envelope) that fix X and yaw when the gripper pushes the die home with 0.25 N, a −X guard at 0.4 mm and Y guards 0.6 mm outside the facets at the die corners only; (c) **6061 T‑riser / heat sink**: 10 mm wide neck (the fiber holders come to 5 mm from the facets), 15 × 15 mm TEC pocket at Z −12, wire channel, bolt pattern for the B3 kinematic base. Plus a **15 × 15 × 2.5 mm micro‑TEC** (Laird OptoTEC OT08 class or TE Technology TE‑63‑1.0‑1.3) and a 10 kΩ glass thermistor; (d) **die stage** under the riser: **Suruga KXC04015‑C** motorized X stage (40 × 40, 15 mm travel, crossed roller, 1 µm half step, runs on the existing DS102 controller #3) carrying a **MISUMI RMPG40W‑N** motorized worm‑gear rotary stage on its table (40 mm class, horizontal table, 35 mm tall, axis through the die, 5‑phase stepper on the DS102's θ axis: nulls the yaw measured fiducial‑to‑fiducial under the microscope, per die) with one 3 mm 6061 adapter plate under the X stage; the nest steps the die from device to device and the gripper meets it at stage home only. The stack needs 100 mm under the die, so both NanoMax stages get 25 mm riser plates (B14) | Protolabs / Xometry CNC (copper and PEEK), pad lapped in‑house after plating (granite plate, 3 µm diamond film) | quote (~$600–1,000 + TEC ~$30; KXC04015‑C ~¥120,000 ≈ $800 list, RMPG40W‑N quote) | 1 set (+1 spare chuck) | 1 wk (Suruga / MISUMI 3–5 days) | The one precision part. Chuck and cage are separate so the pad can be re‑lapped and the cage replaced after wear. The X stage is needed because the NanoMax stages travel only 4 mm and the devices span 8 mm. |
| A5 | Wafer trays | **Custom SLA print**: one tray per wafer, **8 columns × 14 rows = 112 pockets**, 132 × 106 × 3.8 mm (`cad/tray`, print file `cad/tray/STL/wafer_tray_8x14.stl`): ledges 1.0 mm wide under the facet‑edge strips, 0.8 mm tall; end walls at ±1.0 mm retaining the die by its corners, 3.6 mm nose slots in each end wall (a through channel along each column); Y walls at 0.4 mm clearance; lid; DataMatrix on the rim. Pocket (row, col) mirrors the wafer map. Material: Formlabs **Rigid 10K** if a Form 3/4 is in house, else Protolabs Accura Xtreme / Somos WaterShed | In‑house printer or Protolabs SLA | ~$120–250 each | 4 | 2–4 days | One wafer = one tray; dies return to their own pocket after test. Cheap enough to iterate weekly. |
| A6 | Compressed air (if no house air) | **California Air Tools 1P1060S** (0.6 hp, 1 gal, 56 dBA, oil‑free) + **SMC AW20‑N02‑Z‑A** filter‑regulator | Home Depot / Walmart / Ace; SMC distributors | $149–159 compressor; ~$60 FR | 1 | in stock | Quiet enough for an optics lab; avoids the electric‑gripper alternative (Schunk EGP 25: 20–40 N min force, ~$1.5–2 k, 2–4 wk; Zimmer GEP2010: 50–200 N, $2,100 — both far too strong without the flexure). |
| A7 | Vacuum source (if no house vacuum) | **KNF N86 KN.18** diaphragm pump (6 L/min, 100 mbar ultimate) | KNF / lab suppliers (~$300 new EU list; US new quote; used ~$240) | ~$300–450 | 1 | in stock | Chuck hold and seat sensing only need ~−60 kPa. |
| A8 | Test dies — silicon blanks | **UniversityWafer** 100 mm Si, 500 µm, DSP (e.g., FZ undoped <100>, $43.90 ea, MOQ 25 for that SKU; single‑wafer SKUs exist) → dice to 10 × 6 mm at **American Precision Dicing, San Jose** on UV tape, cure + expand before shipping | UniversityWafer; APD | wafer ~$44–80; dicing **quote** (~$150–300/wafer) | 2 wafers (~200 dies) | 1 wk | Cycling blanks. Also the first real "diced wafer on expanded UV tape" to practice on. |
| A9 | Test dies — LN blanks | 3″ or 4″ **X‑cut LiNbO₃, 0.5 mm, DSP** (Precision Micro‑Optics, MTI Corp, Crystro, UniversityWafer) → dice as A8 | PMO / MTI / Crystro; APD | **quote** (~$150–400/wafer) | 1 wafer | 1–2 wk | Realistic contact stress and pyroelectric behaviour for Gate 1. |
| A10 | Bench ionizer | **Simco‑Ion Aerostat PC2** benchtop ionizing blower (91‑PC2‑US‑01), 120 V | TEquipment / TestEquity / ISC Sales | $1,096 | 1 | in stock | LN charges with every temperature change; required before real dies are cycled. |

## B. Order in week 1 (short lead, needed for the manual rig and pneumatics)

| # | Item | Exact part | Vendor | Unit price | Qty | Notes |
|---|---|---|---|---|---|---|
| B1 | Manual XYZ for the hand‑cycling rig | **Thorlabs PT3** (1″ XYZ, ¼‑20) or **PT3/M** | Thorlabs / Fisher | $1,350 | 1 (skip if in stock) | Carries the gripper over nest and tray for Gate 1. |
| B2 | Rig plate | **Thorlabs MB1218** 12 × 18″ breadboard | Thorlabs / Fisher | $281 | 1 | Common plate for nest, tray, manual stage; later the robot bench. |
| B3 | Nest kinematic base | **Thorlabs KB1X1** (or KB1X1/M) kinematic base | Thorlabs | ~$150 | 1 | Lets the nest move between rig and tester and return repeatably. |
| B4 | Right‑angle bracket + posts for the gripper | Thorlabs **AP90**, **RS2P**, **TR75** as needed | Thorlabs | ~$150 total | — | |
| B5 | Gripper valve | **SMC SY3120‑5LZ‑M5** (5/2, 24 VDC, M5 ports) | Zoro / RS / Automation Distribution | $48–67 | 2 | One for the gripper, one spare (or as 3/2 for vacuum). |
| B6 | Vacuum valve | **SMC VQ110‑5L‑M5** (3/2, 24 VDC) or a second SY3120 plumbed 3‑port | SMC distributors | ~$50–70 | 1 | Nest chuck vacuum on/off. |
| B6a | Blow‑off valve | second **SMC VQ110‑5L‑M5** from a regulator set to a few kPa (SMC IR1000 class) into the chuck line | SMC distributors | ~$50–70 + regulator | 1 | Positive release before picking from the lapped pad (`docs/pick_and_place_design.md` §3.4). |
| B6b | Jaw speed controllers | 2 × meter‑out speed controllers for the MHZ2‑6D's M3 ports (SMC **AS1201F‑M3‑04** class; confirm the thread) | SMC distributors | ~$30 | 2 | Finger speed ≤ 10 mm/s at closing and opening (`docs/pick_and_place_design.md` §3). |
| B7 | Precision regulator (gripper supply) | **SMC IR1000‑01** (0.005–0.2 MPa) — or **IR1010‑01** (0.01–0.4 MPa) for headroom | SMC distributors / Automation Distribution | ~$120–180 | 1 | Gripper runs at 0.15–0.2 MPa; force still comes from the flexure. |
| B8 | Vacuum switch (seat sensing) | **SMC ZSE30A‑01‑N‑L** (or ‑N01‑P for PNP, NPT) digital vacuum switch, 0 to −101 kPa | Next Day Automation / Automation Distribution | $60–85 | 1 | Threshold output → controller / DAQ digital input (via isolator). |
| B9 | Fittings & tubing | SMC **KQ2H04‑M5** (M5 → Ø4 one‑touch) ×10, **KQ2H04‑01S** ×4, **TU0425BU‑20** Ø4 PU tubing 20 m, **KQ2T04‑00A** tees ×4 | SMC distributors / McMaster | ~$80 | — | |
| B10 | 24 V supply + I/O | **Mean Well LRS‑50‑24**; if using the NI USB‑6363 for valves/sensors add a 4‑ch 24 V relay/isolator module (e.g., Phoenix Contact PLC‑RSC‑24DC/21 ×2 for valves, and 24 V→5 V optocoupler inputs for the M9 switches) | Digi‑Key / Mouser | ~$80 | 1 | Zaber and Thorlabs controllers also expose digital I/O usable for the valves. |
| B11 | Jaw force check | **American Weigh Scales GEMINI‑20** (0.001 g pocket scale) | Amazon | ~$25 | 1 | 0.3 N = 30 g on the pan; sets the flexure preload. |
| B12 | End‑face tweezers (manual tray loading) | **Ideal‑tek 2ACFR.SA.1** with **A2ACF** carbon‑fiber flat tips | TestEquity / TEquipment | ~$50 | 3 | The only approved hand tool near dies: flat ESD tips on the end faces. |
| B13 | Bench inspection camera | **Dino‑Lite AM7915MZT** (5 MP, 20–220×, EDOF) | Mega Depot / Microscope.com | **quote** (~$900–1,100) | 1 (optional) | Only if the existing microscope cannot be used at the bench rig. |
| B14 | Axis mounting | 6061 riser bars under the two horizontal actuators (X: 40 × 118 × 300 mm under the base rail, motor overhanging; Y: 60 × 63 × 200 mm), the 60 × 60 × 10 angle bracket carrying the Z actuator on the X table plate, the one‑piece arm (33‑deep adapter block, 25 mm square bar, 8 mm end plate) on the Z table plate, the 8 mm tray deck with its locating pocket on the Y table plate; 25 mm riser plates under both NanoMax stages. All exported as STEP + STL by `cad/station`; print in PPA‑CF for the prototype per `docs/print_list.md`, machine after the trials | McMaster bar stock + in‑house tapping (or 80/20 40 × 120 profile for the X riser) | ~$250 | 1 | X actuator along the exchange direction beside the input NanoMax (centre-line Y −140), outside both fiber corridors; bolt patterns from the LX20 catalog (base Ø3.4 through on a 60 mm pitch, table 4 × M4 on 33.2 × 20). |

## C. Not this month — price‑checked for Month 2 planning

| Item | Part | Price / lead | Use |
|---|---|---|---|
| Production transfer axes | Longer versions of A1 for a second tray position (X +130 mm: LX26 or LX30 class, since the LX20 tops out at 236.5 mm stroke), same motors and software | quote (~$4–6 k) | Scale‑up of the Month‑1 Cartesian; a SCARA (Epson T3‑B, $7,495) is only an option with an offset gripper bar, since its vertical quill lands at the die end where the objective barrel is. |
| Film‑frame expander (if the vendor does not pre‑expand) | **Dynatex DXE 5** (≤ 150 mm) or **DXE 9** (≤ 200 mm); **Ultron UH130** semi‑automatic | quote (used manual units ~$2–5 k) | Sorting station. |
| UV cure box (if the vendor does not pre‑cure) | **Ultron UH102‑8** | quote (used units on eBay) | Sorting station. |
| Electric gripper (only if air proves impossible) | **Schunk EGP 25‑N‑N‑B** (3 mm/jaw, 20–40 N) | ~$1.5–2 k, 2–4 wk | Same flexure fingers; force still spring‑limited. |
| Machined PEEK wafer trays | Semitron ESd 480 or natural PEEK, CNC | quote | Replace SLA trays after the pocket design settles. |

---

## D. Should die sorting (tape → wafer trays) be outsourced to the dicing company?

**Recommendation: keep the pick itself in‑house; outsource only the tape preparation.**

What the local vendors actually offer (checked): American Precision Dicing (San Jose)
extracts from standard and UV tape into waffle packs, Gel‑Pak, vacuum‑release Gel‑Pak,
trays, film frames **and customer‑supplied custom containers**, with manual,
semi‑automatic and automated workflows, wafer‑map handling and inspection for chips and
sidewall fractures. American Dicing (NY) offers "manual pick and place for
pressure‑sensitive parts" and multiple needle/collet configurations. Neither publishes
what touches the die: the industry default is a **vacuum collet on the top surface**,
which is exactly what air‑clad waveguides forbid.

| | Outsource the pick | In‑house |
|---|---|---|
| Control of the one fragile step | Their operator, their tool, no way to see it | Your procedure, your jaws, inspect every 50 |
| Top‑surface risk | Default tooling is a top collet; edge‑only must be specified, tooled and audited | Zero by design (end‑face jaws / end‑face tweezers) |
| Iteration speed | Weeks per lot | Same day |
| Throughput needed | ~300 dies/batch | ~1 min/die manual ⇒ ~5 h per batch — not the bottleneck against hours‑per‑die test time |
| Cost | Manual sort typically a few $/die + NRE for custom carriers (quote) | Tech time; hardware already bought for the tester |
| Traceability | Wafer map → carrier map supplied | Wafer map → tray map, same |

So:

1. **Now (Month 1–2):** have the vendor dice on **UV‑release tape, UV‑cure, and expand
   the frame before shipping** (all standard services, cheap). Sort in‑house by hand:
   end‑face tweezers or the gripper on the manual XYZ, needle‑eject from below where
   needed, into the wafer tray. Five hours per 300‑die batch is acceptable and it is the
   same handling you do today, only safer.
2. **Month 2–3:** semi‑automate in‑house with the **same Cartesian axes and gripper** you already
   own, plus a manual ejector under the frame — the incremental cost is a used expander
   (or none if the vendor keeps expanding for you).
3. **In parallel, qualify APD as a backup:** give them two trays, two pairs of end‑face
   tweezers and a one‑page procedure (end faces only, middle 3 mm, no top contact, no
   facet contact), and inspect the first 50 dies they return. If they pass, they become
   the overflow path; if not, you have lost nothing.
4. **Do not buy an automated sorting station** (expander + UV + custom head) until
   Month 3 volumes justify it. It is the least‑used machine in the whole system.

The reason to keep it in‑house is not cost. It is that the facet‑ and top‑surface rules
cannot be verified from outside, and the tray pockets and jaw geometry are still changing
weekly.

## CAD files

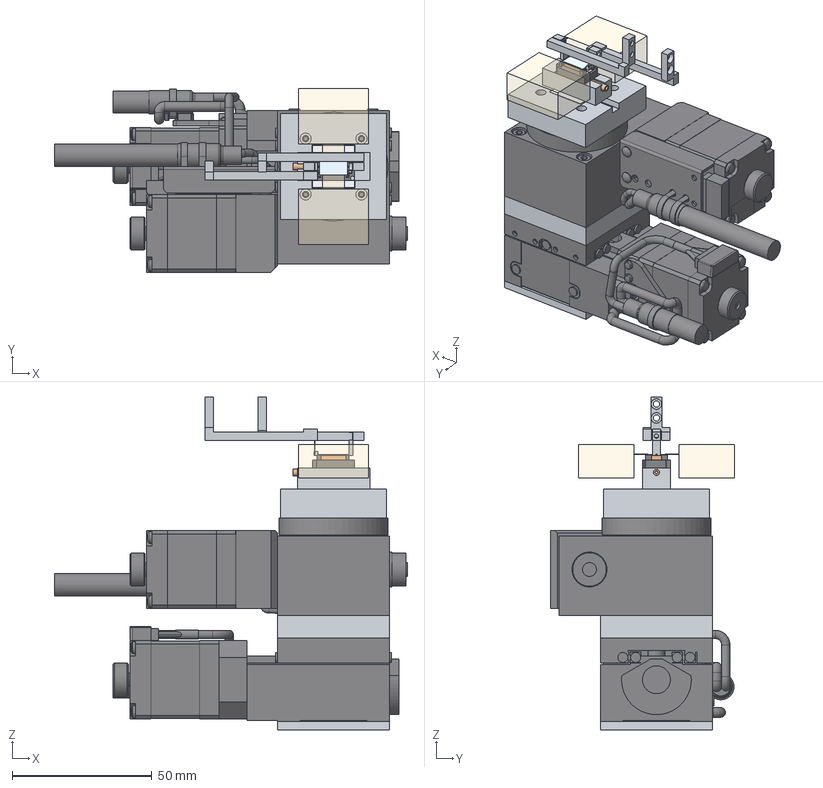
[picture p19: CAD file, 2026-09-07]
cad/nest/STEP/nest_module_assembly.step
126.5 x 66.0 x 119.3 mm
nest_chuck_copper
nest_cage_semitron
nest_riser_6061
nest_adapter_kb_kxc
nest_spacer_kxc_rot
tec_15x15
kxc04015_base
kxc04015_table
kxc04015_coupling x 2
kxc04015_motor
rmpg40w_body
rmpg40w_table
rmpg40w_bolts
rmpg40w_worm
rmpg40w_motor
rmpg40w_cable
die_seated
gripper_far_tip_closed
gripper_near_tip_closed
gripper_blade_closed
gripper_near_arm_closed
gripper_far_arm_closed
fiber_in
fiber_out
holder_in
holder_out

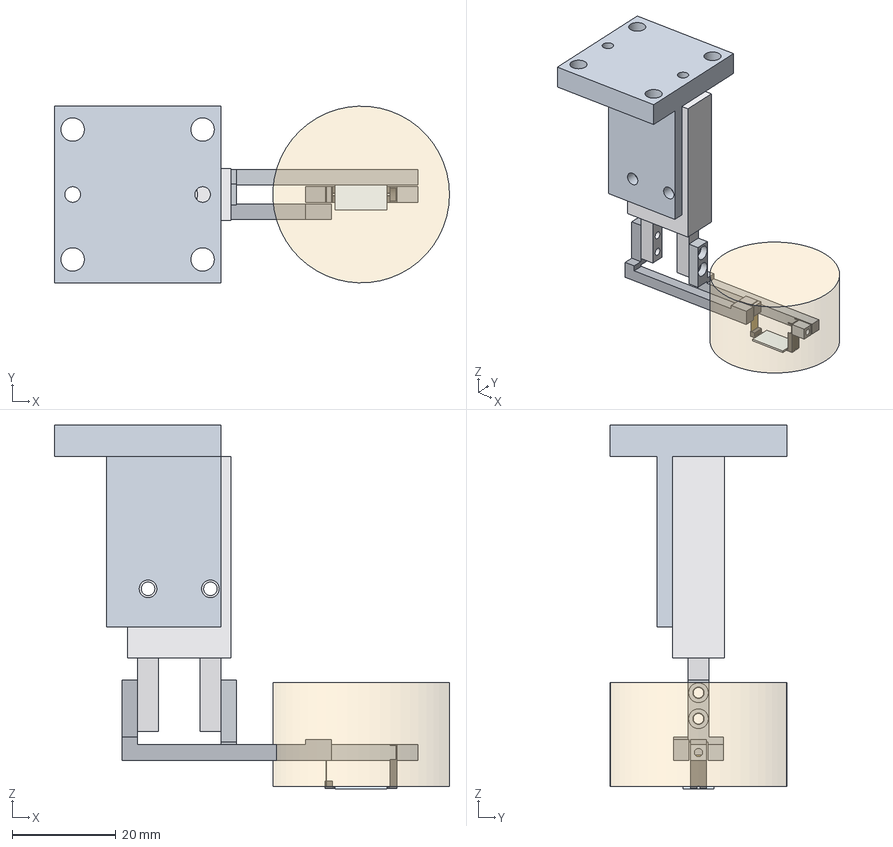
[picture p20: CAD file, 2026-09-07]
cad/gripper/STEP/gripper_module_assembly.step
76.0 x 34.0 x 70.0 mm
far_arm_6061
near_arm_6061
far_tip_block_semitron
near_tip_block_semitron
flexure_blade_0p127_steel
bracket_6061
mhz2_6d_body
mhz2_6d_finger_near
mhz2_6d_finger_far
die_10x6x0p5
objective_keepout_wd20

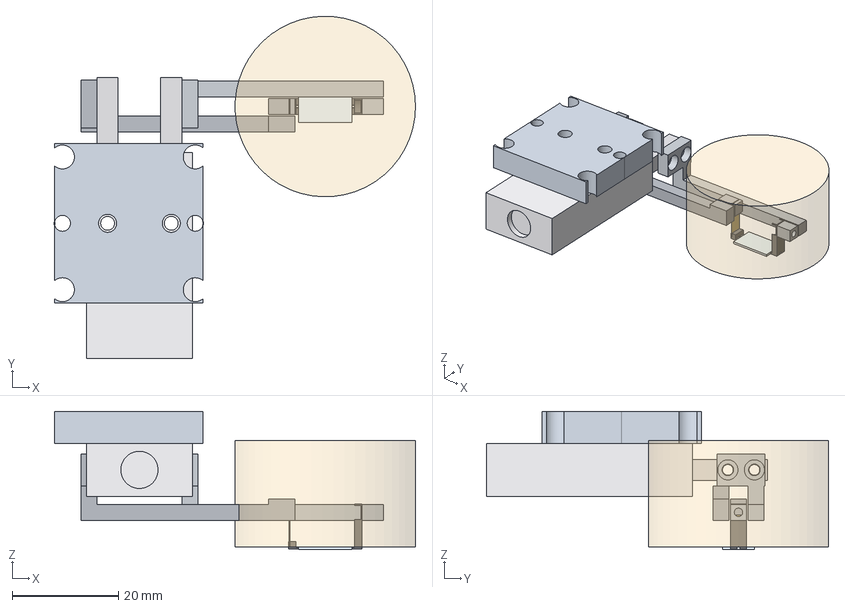
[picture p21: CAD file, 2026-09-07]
cad/gripper/STEP/gripper_module_assembly_h.step
68.0 x 64.5 x 26.0 mm
far_arm_6061_h
near_arm_6061_h
far_tip_block_semitron
near_tip_block_semitron
flexure_blade_0p127_steel
bracket_6061_h
mhz2_6d_body
mhz2_6d_finger_near
mhz2_6d_finger_far
die_10x6x0p5
objective_keepout_wd20

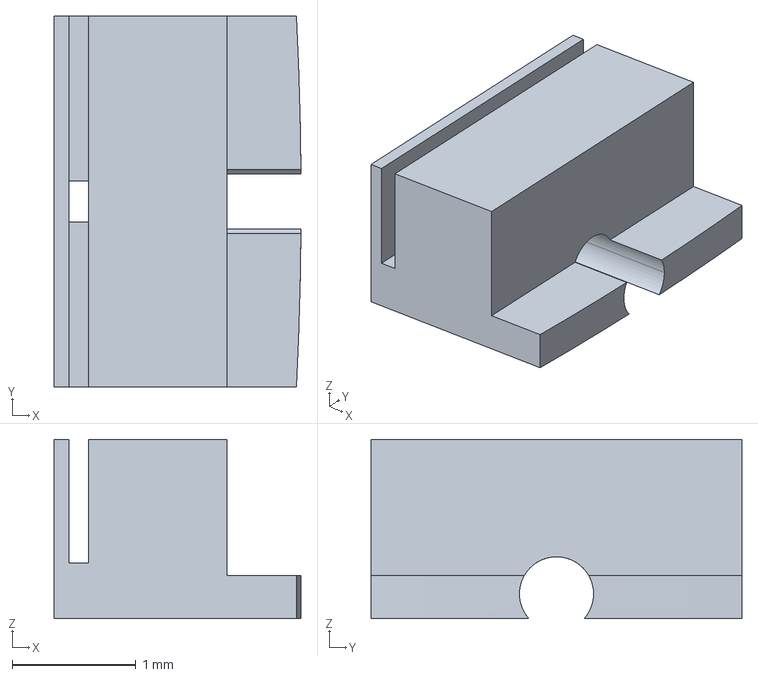
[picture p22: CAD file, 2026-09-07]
cad/gripper/STEP/near_tip_block_semitron.step
2.00 x 3.00 x 1.45 mm

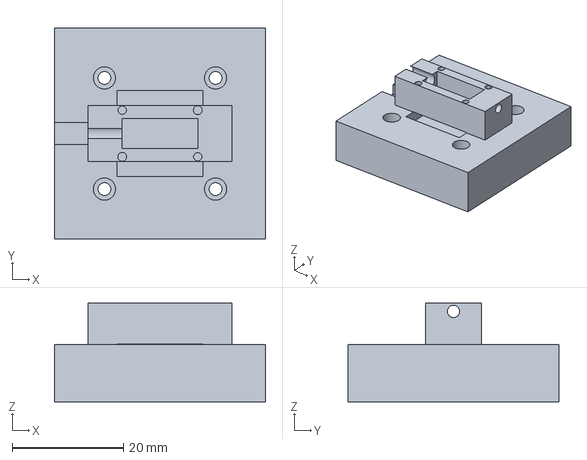
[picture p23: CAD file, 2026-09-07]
cad/nest/STEP/nest_riser_6061.step
38.0 x 38.0 x 17.8 mm

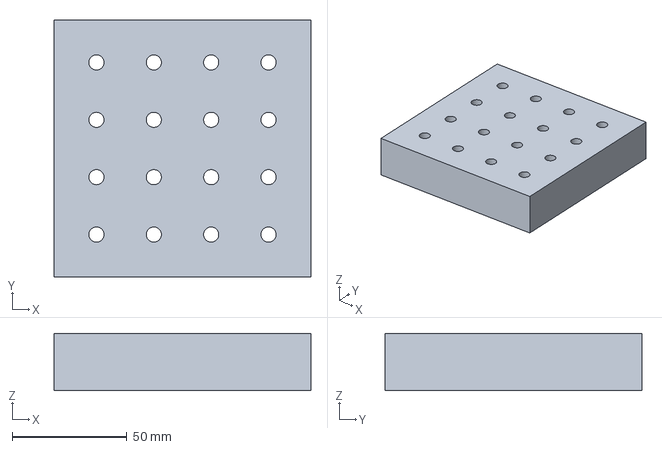
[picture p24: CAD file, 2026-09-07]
cad/station/STEP/nanomax_riser_6061.step
112.0 x 112.0 x 25.0 mm

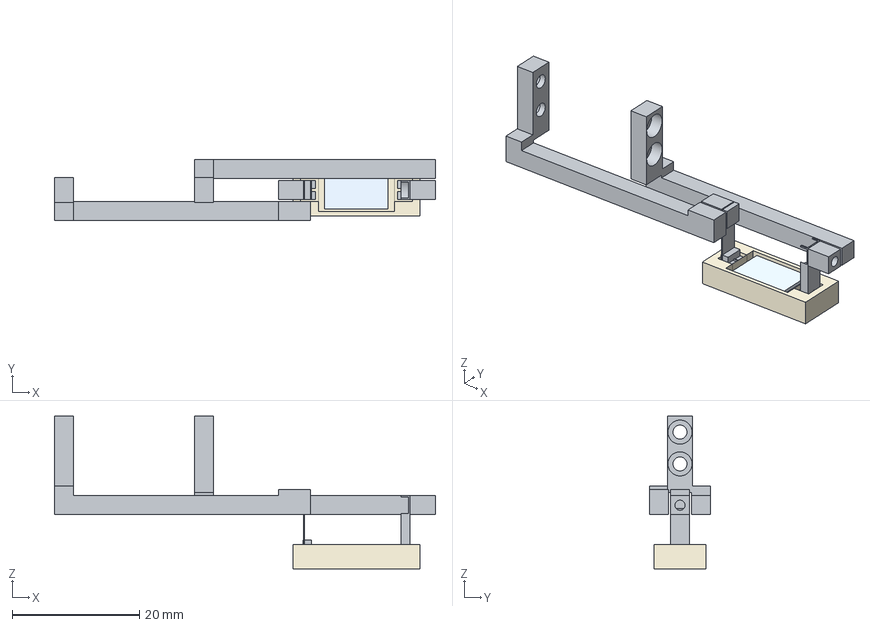
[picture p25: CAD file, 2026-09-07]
cad/tray/STEP/tray_pocket_check.step
59.9 x 9.60 x 24.0 mm
die
near_tip
far_tip
blade
near_arm
far_arm

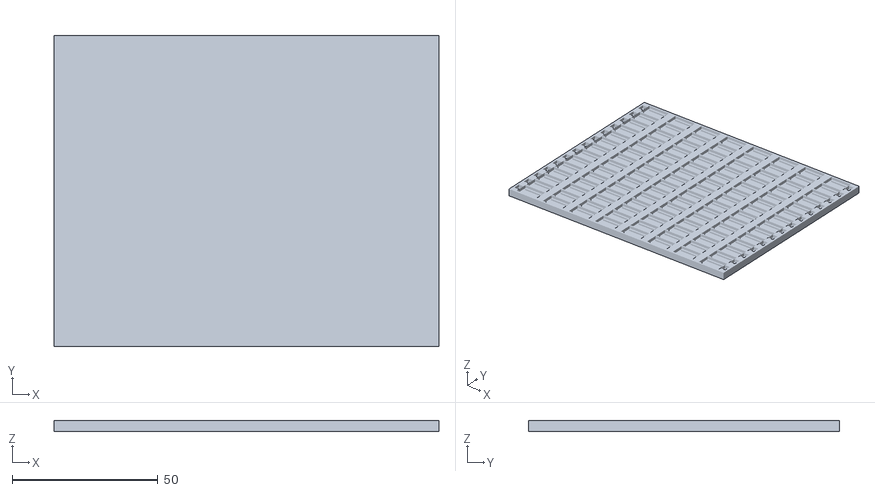
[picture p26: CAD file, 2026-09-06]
cad/tray/STL/wafer_tray_8x14.stl
132.0 x 106.5 x 3.80

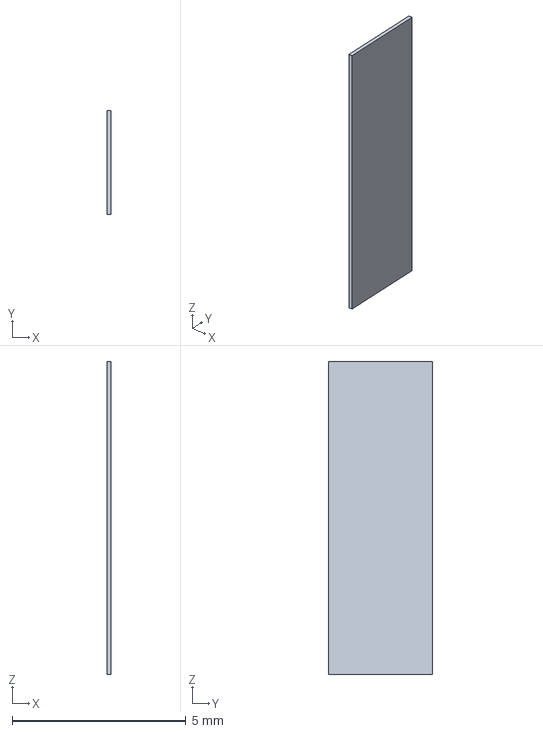
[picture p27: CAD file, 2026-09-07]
cad/gripper/STEP/flexure_blade_0p127_steel.step
0.127 x 3.00 x 9.00 mm

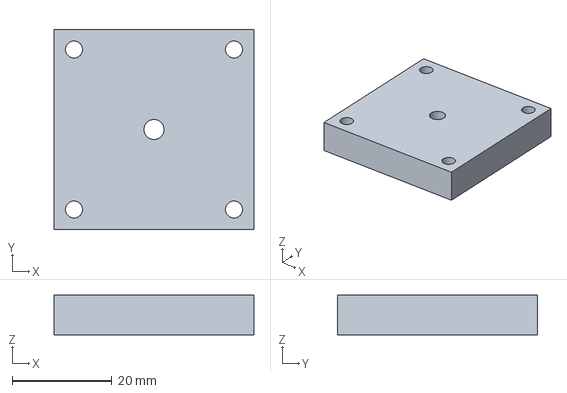
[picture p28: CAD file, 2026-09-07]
cad/nest/STEP/nest_spacer_kxc_rot.step
40.0 x 40.0 x 8.00 mm

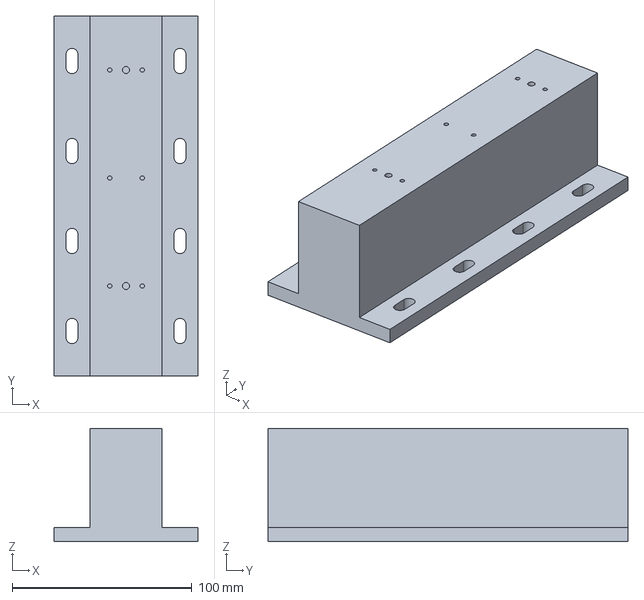
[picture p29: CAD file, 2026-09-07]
cad/station/STEP/y_axis_riser_6061.step
80.0 x 200.0 x 63.0 mm

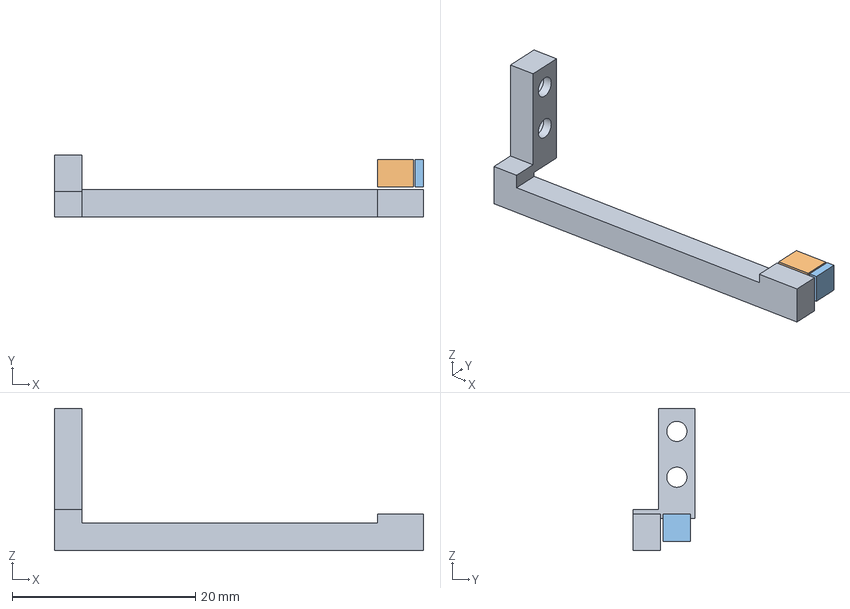
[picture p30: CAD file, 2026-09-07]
cad/gripper/STEP/near_arm_6061.step
40.3 x 6.80 x 15.5 mm

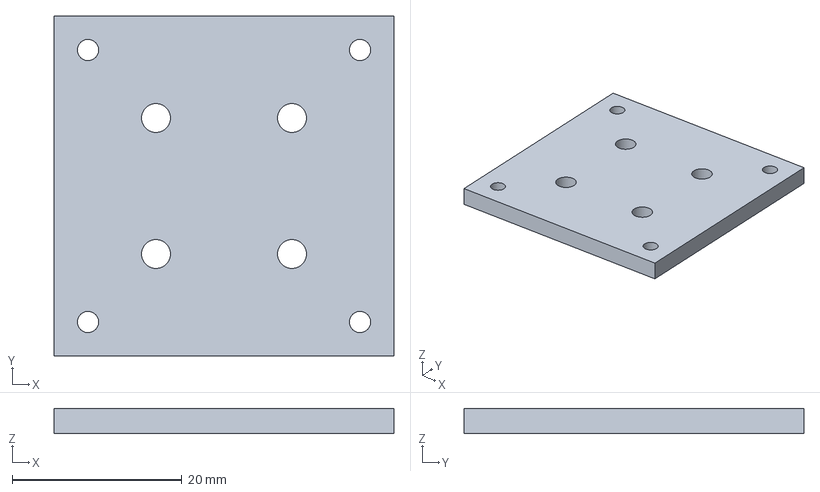
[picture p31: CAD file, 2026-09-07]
cad/nest/STEP/nest_adapter_kb_kxc.step
40.0 x 40.0 x 3.00 mm

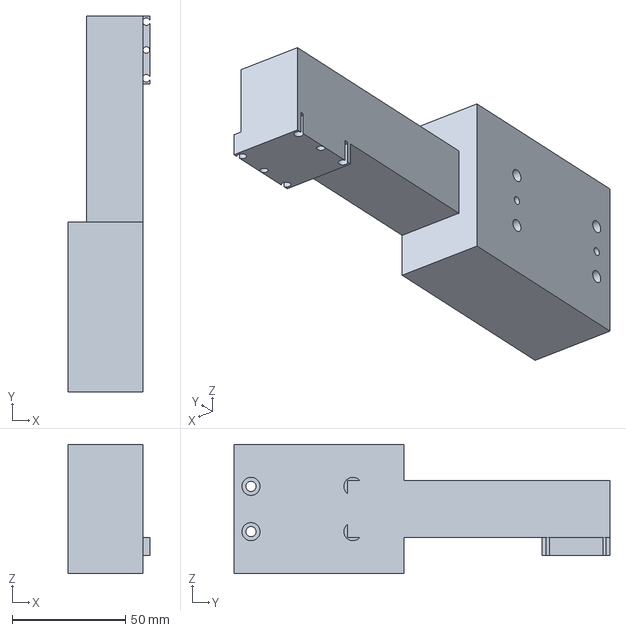
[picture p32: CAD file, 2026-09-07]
cad/station/STEP/arm_6061_h.step
36.0 x 166.0 x 57.0 mm

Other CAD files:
cad/gripper/STEP/far_arm_6061.step
cad/nest/STEP/nest_chuck_copper.step
cad/station/STEP/arm_6061.step
cad/gripper/STEP/bracket_6061_h.step
cad/gripper/STEP/bracket_6061.step
cad/gripper/STEP/far_arm_6061_h.step
cad/gripper/STEP/far_tip_block_semitron.step
cad/gripper/STEP/near_arm_6061_h.step
cad/gripper/STL/bracket_6061.stl
cad/gripper/STL/bracket_6061_h.stl
cad/gripper/STL/far_arm_6061.stl
cad/gripper/STL/far_arm_6061_h.stl
cad/gripper/STL/far_tip_block_semitron.stl
cad/gripper/STL/flexure_blade_0p127_steel.stl
cad/gripper/STL/near_arm_6061.stl
cad/gripper/STL/near_arm_6061_h.stl
cad/gripper/STL/near_tip_block_semitron.stl
cad/nest/STEP/nest_adapter_kb_rpg.step
cad/nest/STEP/nest_cage_semitron.step
cad/nest/STEP/nest_module_setdown.step
cad/nest/STL/nest_adapter_kb_kxc.stl
cad/nest/STL/nest_cage_semitron.stl
cad/nest/STL/nest_chuck_copper.stl
cad/nest/STL/nest_riser_6061.stl
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

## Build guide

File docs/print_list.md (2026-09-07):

# Print list: every custom part, what it is made of, and how to make it

**Status:** rev. 1 (2026-09-07). Companion to the CAD package (`cad/`), which exports one STEP and one STL per
custom part. This list says which parts are printed in **Bambu PPA-CF on the H2C** for the prototype, which
are machined from the start, and what to do to each print before it goes on the machine. The station parts
were sized for the MISUMI LX20 actuators (`cad/station/README.md`); the bolt patterns come from the
manufacturer STEP files.

## 1. Printer settings that apply to every PPA-CF part

- 0.4 mm hardened-steel nozzle, 0.16 mm layers (0.2 for the risers), 5 walls, 4 top/bottom layers, 40 %
  gyroid infill; filament dried; chamber heated; textured PEI plate with glue for the 300 mm bar.
- Holes are modelled at their **finished** size and print about 0.2 mm undersize. Drill or ream every hole
  that takes a bolt or a pin: tap-drill holes (Ø2.5 for M3, Ø3.3 for M4) are tapped directly in PPA-CF, or
  opened to Ø4.0 / Ø5.6 for heat-set inserts where a joint is undone often; dowel holes (Ø2.9 / Ø3.9) are
  reamed to H7 for Ø3 / Ø4 pins; clearance holes (Ø4.5, Ø6.6) are drilled through.
- Mounting faces that meet a stage or a table (the riser tops and feet, the bracket base, the block face on
  the Z table, the deck's pocket floor) get one pass on a surface plate with 400-grit paper so the print's
  top-layer texture does not set the flatness.
- Carbon-filled surfaces must not touch a die anywhere but its backside. None of the parts below touches a
  die; the tray touches the backside only.
- A printed part in the fibre-to-die metrology loop is a fit-check part, not a final part: the NanoMax
  risers and the nest stack adapters swell with humidity by tens of µm and creep under bolt preload.

## 2. Station mounting parts (`cad/station/STL/`)

All new in this revision; they replace the envelope boxes the station model used to carry. Dimensions
are the default (vertical-gripper) layout; the `_h` files are the horizontal-gripper variant of the two
parts that depend on it.

| # | File | Part | Size (mm) | Print orientation | After printing | Bolts | Final |
|---|---|---|---|---|---|---|---|
| S1 | `x_axis_riser_6061.stl` | X riser bar under the X actuator: 40 wide body with a 60 × 8 foot flange | 300 × 60 × 118 | on its side (118 × 300 face down); 0.2 layers; ~0.7 kg | tap 10 × M3 on the top (LX20 base pattern, rows 18 apart, pitch 60); ream 2 × Ø4 pin holes on the centre line; the foot slots take M6 or ¼-20 on a 25 mm / 1″ grid | rail: M3 × 8 SHCS from inside the rail channel; table: 10 × M6 × 16 | 6061 bar 40 × 120 × 300 or an 80/20 40 × 120 profile with a tapped top plate |
| S2 | `y_axis_riser_6061.stl` | Y riser bar under the Y actuator: 40 wide body, 80 × 8 foot flange | 200 × 80 × 63 | flat on the flange | tap 6 × M3 (top), ream 2 × Ø4 | as S1 (6 × M3, 6 × M6) | 6061 bar |
| S3 | `tower_bracket_6061.stl` | Angle bracket on the X table plate carrying the Z actuator: 60 × 60 × 10 base, 10 mm leg, gusset rib | 60 × 60 × 110 | base plate down, leg up (rib is self-supporting at 56°) | drill 4 × Ø4.5 + Ø8 counterbore (table pattern 20 × 45), ream 2 × Ø3 dowels in the base; tap 4 × M3 in the leg's +X face (Z rail base pattern), ream 2 × Ø4 pins | X table: 4 × M4 × 10 SHCS + 2 × Ø3 × 8 dowels; Z rail: M3 × 8 from inside its channel | 6061, machined from a 60 × 60 × 110 block or welded angle |
| S4 | `arm_6061.stl` (`arm_6061_h.stl`) | One-piece arm: 33-deep adapter block on the Z table, 25 sq bar along +Y, 8 mm end plate over the gripper bracket | 71 × 191 × 57 (block 33 × 71 × 57, bar 25 × 25 × 171) | station −X face down: block and bar both rest on the bed, the end plate stands as a wall; no supports | drill 4 × Ø4.5 through the block (counterbored Ø8 from the outside, 25 deep), ream 2 × Ø3 dowels in the block face; tap 4 × M4 in the end plate, ream its 2 × Ø3 dowels | Z table: 4 × M4 × 40 SHCS + 2 × Ø3 × 8 dowels; gripper bracket: 4 × M4 × 16 from below + 2 × Ø3 × 10 dowels | 6061; the bar can be a stock 25 sq bar bolted into a machined block |
| S5 | `tray_deck_6061.stl` | Tray deck on the Y table plate with a 2 mm locating pocket for the tray (0.2 mm clearance per side) | 148 × 122 × 8 | flat, pocket up | drill 4 × Ø4.5 + Ø8 counterbore from the pocket floor (Y table pattern 20 × 45), ream 2 × Ø3 dowels; check the pocket floor flat within 0.05 mm, since it sets the ledge height | Y table: 4 × M4 × 10 SHCS + 2 × Ø3 × 8 dowels | 6061 plate, or keep the print if the pocket floor measures flat |
| S6 | `nanomax_riser_6061.stl` (×2) | 25 mm riser plate under each NanoMax, Ø6.6 through holes on the 25 mm grid | 112 × 112 × 25 | flat | drill the 16 holes through | M6 × 50 SHCS through the NanoMax slots and the plate into the table | **6061 plate, final** (metrology loop); print only for the fit check |

Bolt lengths assume 1 mm of washer; check each against the tapped depth before ordering.

## 3. Gripper (`cad/gripper/STL/`)

| # | File | Part | Prototype | After printing | Final |
|---|---|---|---|---|---|
| G1 | `bracket_6061.stl` (`_h`) | L-bracket between the SMC body and the arm end plate | print, bracket plate down | drill 2 × Ø3.4 (M3 through the SMC body), 4 × Ø4.5 (interface), ream 2 × Ø3 dowels | 6061 |
| G2 | `far_arm_6061.stl` (`_h`) | rigid arm, 3 × 3 bar, head with the tip-block thread | print, bar flat on the bed | drill the 2 × Ø2.2 root holes, tap M2 in the head | 6061, hard anodised |
| G3 | `near_arm_6061.stl` (`_h`) | compliant arm with the blade slot | print, bar flat | the 0.18 mm slot does not print: print it 0.5 wide and pot the blade with the M2 clamp screw | 6061 |
| G4 | `far_tip_block_semitron.stl`, `near_tip_block_semitron.stl` | crowned noses | **machine now** (Semitron ESd 480): sub-0.1 mm features, and carbon-filled surfaces would abrade the die end faces | — | same |
| G5 | `flexure_blade_0p127_steel.stl` | blade | cut from 0.005″ feeler stock | — | same |

## 4. Nest (`cad/nest/STL/`)

| # | File | Part | Prototype | Final |
|---|---|---|---|---|
| N1 | `nest_riser_6061.stl` | T-riser with the TEC pocket | print for fit and cold trials (rotary table pattern 8 × M2: drill Ø2.2 counterbored) | 6061: it carries the TEC heat |
| N2 | `nest_adapter_kb_kxc.stl` | 3 mm plate KB1X1 → X stage | print for fit (tap 4 × M3) | 6061 or waterjet; metrology loop |
| N3 | `nest_spacer_kxc_rot.stl` | 8 mm spacer X stage → rotary, Ø4 centre dowel | print for fit (drill 4 × Ø3.4, ream Ø4) | 6061; metrology loop |
| N4 | `nest_cage_semitron.stl` | cage with stop pads and guards | print a **coarse** version for sequence rehearsal on silicon blanks only (guards 0.6 mm from the facets and 0.4 mm pads do not print to tolerance) | Semitron ESd 480, machined |
| N5 | `nest_chuck_copper.stl` | lapped vacuum chuck | **machine now**: vacuum-tight, flat to 3 µm, thermal path | C101, Ni plated, lapped |

## 5. Tray (`cad/tray/STL/`)

| # | File | Part | Prototype | After printing | Final |
|---|---|---|---|---|---|
| T1 | `wafer_tray_8x14.stl` | 112-pocket wafer tray | print flat, 0.16 layers, 0.4 nozzle (ledges 1.0 × 0.8 mm) | measure the ledge plane with an indicator: flat within 0.1 mm over 132 mm, else skim or reprint; check surface resistance of a coupon | print (PPA-CF), or Semitron if flatness or ESD fail |

## 6. Order of printing

1. Tray, gripper bracket and arms, tower bracket, arm, deck: the hand-cycling rig and the sequence
   rehearsal need these first. Machine the two tip blocks and the chuck in parallel.
2. X and Y risers once the LX20 actuators are in hand, so the base-hole positions can be checked against
   the real rails before tapping.
3. NanoMax risers and nest adapters as fit checks only; order the aluminium versions with the chuck.

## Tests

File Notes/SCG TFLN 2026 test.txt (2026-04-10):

1-23-26

10 dBm from TSL-770 directly connected to lensed fiber,
-----------------------------------------------------------------------------------------------
D02P08

only 3.42V max voltage from photodetector at gain = 100 corresponds to 78 uW; approx < 21 dB loss?
------------------------------------------------------------------------------------------------
D02P09

0.55 V from PD at gain = 10, corresponds to 100 uW; 

After connecting to all the modulator setup at CW pow 12 dBm

0.713 V from PD at gain = 100, corresponds to 13 uW; approx. 21.5 dB

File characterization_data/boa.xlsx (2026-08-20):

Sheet: Sheet1
Wavelength (nm) | Output power (mW) | Gain (dB) | NOTE: Input power is 0 dBm, 278.8 mA
1480 | 2.35 | 3.710678623
1490 | 4.38 | 6.414741105
1500 | 7.26 | 8.609366207
1510 | 10.7 | 10.29383778
1520 | 14.46 | 11.60168293
1530 | 18.36 | 12.63872677
1540 | 22.5 | 13.52182518
1550 | 26.5 | 14.23245874
1560 | 30 | 14.77121255
1570 | 32.18 | 15.0758604
1580 | 32.74 | 15.15078675
1590 | 31.34 | 14.96098992
1600 | 28.3 | 14.51786436
1610 | 23.55 | 13.71990911
1620 | 16.46 | 12.16429831
1630 | 8.7 | 9.395192526

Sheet: Sheet2
1560 nm | 40 mW @ 347 mA, 30 mW at 278.7 mA, 20 mW at 213.2 mA
Current (mA) | Output power (mW) | Gain (dB) | output power after lensed fiber
78 | 1 | 0 | 1.37
100 | 3.17 | 5.010592622 | 2.42
150 | 10.4 | 10.17033339 | 5.39
200 | 18 | 12.55272505
250 | 25.75 | 14.10777233
300 | 33.4 | 15.23746467
350 | 40.5 | 16.07455023
400 | 47.5 | 16.7669361
450 | 54.1 | 17.33197265
500 | 60 | 17.7815125
550 | 66 | 18.19543936
600 | 71.7 | 18.55519156

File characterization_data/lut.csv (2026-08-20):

1.50E-06 | 1.94E-01 | 9.21E-04
1.50E-06 | 1.93E-01 | 1.12E-03
1.51E-06 | 2.04E-01 | 1.18E-03
1.52E-06 | 2.09E-01 | 1.22E-03
1.52E-06 | 2.09E-01 | 1.21E-03
1.53E-06 | 2.12E-01 | 1.23E-03
1.53E-06 | 2.06E-01 | 1.18E-03
1.53E-06 | 2.07E-01 | 1.19E-03
1.54E-06 | 2.16E-01 | 1.24E-03
1.55E-06 | 2.17E-01 | 1.23E-03
1.55E-06 | 2.28E-01 | 1.28E-03
1.55E-06 | 2.23E-01 | 1.25E-03
1.56E-06 | 2.30E-01 | 1.28E-03
1.57E-06 | 2.29E-01 | 1.28E-03
1.57E-06 | 2.33E-01 | 1.28E-03
1.57E-06 | 2.33E-01 | 1.27E-03
1.58E-06 | 2.28E-01 | 1.23E-03
1.59E-06 | 2.29E-01 | 1.24E-03
1.59E-06 | 2.38E-01 | 1.28E-03
1.59E-06 | 2.36E-01 | 1.26E-03
1.60E-06 | 2.34E-01 | 1.25E-03
1.60E-06 | 2.33E-01 | 1.25E-03
1.61E-06 | 2.31E-01 | 1.23E-03
1.61E-06 | 2.37E-01 | 1.28E-03
1.62E-06 | 2.39E-01 | 1.28E-03

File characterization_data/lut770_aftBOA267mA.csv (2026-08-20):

# Wavelength(um) | Tapvolt(V) | Power(W)
1.500000000000000038e-06 | 2.149055368473458127e-01 | 9.982076470000000173e-03
1.501000000000000113e-06 | 2.153853195316163815e-01 | 1.035895109999999952e-02
1.502000000000000188e-06 | 2.163352248464534278e-01 | 1.070959399999999936e-02
1.503000000000000263e-06 | 2.213809930861111996e-01 | 1.119676510000000048e-02
1.504000000000000339e-06 | 2.167393371076546116e-01 | 1.148413310000000014e-02
1.505000000000000414e-06 | 2.129864061114699336e-01 | 1.177378089999999919e-02
1.506000000000000489e-06 | 2.155575904954612487e-01 | 1.218330389999999937e-02
1.507000000000000564e-06 | 2.249680931703252895e-01 | 1.272509429999999983e-02
1.508000000000000639e-06 | 2.259840088597171726e-01 | 1.311748010000000041e-02
1.509000000000000714e-06 | 2.231761531363711526e-01 | 1.342040859999999933e-02
1.510000000000000789e-06 | 2.197822541369871541e-01 | 1.374383180000000003e-02
1.511000000000000864e-06 | 2.202942370027228813e-01 | 1.409835459999999978e-02
1.512000000000000940e-06 | 2.265909822592039602e-01 | 1.457862839999999986e-02
1.513000000000001015e-06 | 2.263768510598861416e-01 | 1.493002099999999992e-02
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

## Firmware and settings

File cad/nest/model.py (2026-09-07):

"""
Self-registering, temperature-controlled nest ("chip stage") for the die tester.

The die is set down by the end-face gripper onto a lapped copper vacuum chuck pad and then
pushed, by the gripper's own compliant nose, against two hard-stop pads on its +X end face.
The stop pads fix X and yaw mechanically; the chuck pad fixes Z, pitch and roll; Y is left
free (the fiber stages approach along Y and measure the gap anyway) but is caged to
+/-0.6 mm by four corner blocks that never touch the die in normal operation.

Fiber access: the fiber tips protrude only ~5 mm from their holders, so the holder bodies
come to Y -5 and Y +11 (facets at Y 0 and 6). Nothing of the nest may be in that space:
the nest is a 10 mm wide neck (Y -2..8) down to below the holders' underside, and only
widens (for the TEC and the mounting) further down. Nothing ever stands in front of a
facet where a fiber can go (X 1..9); nothing touches the top surface.

Thermal: the chuck pad is the top of a copper block (Ni-plated) whose neck passes through
the riser to a 15 x 15 mm TEC in the riser's wide section; the aluminium riser is the hot-
side heat sink. Vacuum reaches the pad through 6 holes and a plenum in the copper block,
exiting as a stub tube on the -X side; a thermistor bore enters from +X.

Die stage (the nest moves): the devices span ~8 mm along X but the fiber stages only travel
4 mm, so the die is stepped from device to device by a Suruga KXC04015-C X stage under the
nest (15 mm travel, DS102-driven, 1 um half step), exactly as the current tester does with its
centre stage. A MISUMI RMPG40W-N motorized worm-gear rotary stage (40 mm class, horizontal table,
5-phase stepper on the DS102's second axis) sits ON TOP of the X stage, axis through the die centre.
Yaw is measured by driving the X stage from one end fiducial to the other under the fixed microscope
and reading the lateral offset; that offset is the die's yaw RELATIVE TO THE STAGE TRAVEL, so the
rotary must turn the die relative to the travel, i.e. sit above the X stage (below it, die and travel
would turn together and the offset would not change). The stack from the table up: KB1X1 kinematic
base, 3 mm adapter, KXC04015-C (30 tall), RMPG40W-N (35, bolted straight to the X-stage table: its
4 x M3 on 32 x 32 match the table's M3 grid), riser (4 x M2 into the rotary's 39 sq table), cage/chuck.
Both motors point -X (the only free direction: +X is the microscope column, +/-Y the fiber stages);
the rotary's body is longer on its motor side, which is turned toward -Y, and it rides on the X stage.
The stack needs 100 mm under the die, so the fiber stages and the Y stage sit on 25 mm risers
(common.NANOMAX_RISER) and the table plane is at Z -111. The gripper meets the nest only at the stage
HOME position; the exchange sequence homes the stage first and the fence enforces it.

Frame, die and contact rules: cad/common (X die long axis, Y optical axis, Z up, die bottom at the nest = 0).
The gripper parts used for the checks come from cad/gripper.

Outputs (this folder):
  STEP/nest_chuck_copper.step (+STL/)   C101 copper, Ni plated, pad lapped flat <= 3 um; 6 x dia 0.5 vacuum holes
  STEP/nest_cage_semitron.step (+STL/)  Semitron ESd 480 frame: 4 corner blocks (X stop pads, X guard, Y guards)
  STEP/nest_riser_6061.step             T-shaped riser / heat sink: 10 mm neck, TEC pocket, 4 x M2 cbore to the RMPG40W-N table
  STEP/nest_adapter_kb_kxc.step         adapter plate KB1X1 -> KXC04015-C base  (6061, 3 mm, 4 x M3 tapped on 32 sq)
  STEP/nest_spacer_kxc_rot.step         spacer X-stage table -> RMPG40W-N base  (6061, 8 mm, dia 3.4 x 4 on 32 sq, dia 4 dowel)
  STEP/nest_module_assembly.step        chuck + cage + riser + TEC + die stage stack (vendor STEP where present) + die + gripper (closed) + envelopes
  STEP/nest_module_setdown.step         same with the jaws open at the set-down position (push step)
  checks.txt                            clearances vs gripper (closed / open / push), holders, fibers, die; stage at home and +/-travel

Run:  python cad/nest/model.py   (or python cad/build.py)
"""
from __future__ import annotations
import os
import sys
import cadquery as cq

sys.path.insert(0, os.path.dirname(os.path.dirname(os.path.abspath(__file__))))   # cad/
import common as C                                                             # noqa: E402
from common import box, cyl_x, cyl_z, bb, gap                                  # noqa: E402
from gripper import model as G                                                 # noqa: E402

DIRS = C.out_dirs(__file__)
L, W, T = C.DIE_LEN, C.DIE_WID, C.DIE_THK               # 10, 6, 0.5

N = dict(
    # --- fiber side (single source: common.FIBER; measure on the bench) ---
    fiber_protrusion=C.FIBER["protrusion"],
    holder_w=C.FIBER["holder_w"],
    holder_zb=C.FIBER["holder_zb"], holder_zt=C.FIBER["holder_zt"],
    holder_len=C.FIBER["holder_len"],
    # --- chuck pad: lapped copper, 0.5 mm inboard of every die edge -> 9 x 5 mm = 75 % of the backside ---
    pad=(0.5, 9.5, 0.5, 5.5), pad_z=(-1.5, 0.0),
    vac_holes=((2.0, 1.5), (5.0, 1.5), (8.0, 1.5), (2.0, 4.5), (5.0, 4.5), (8.0, 4.5)), vac_d=0.5,
    plenum=(1.5, 8.5, 1.0, 5.0, -3.0, -2.0),
    # copper block: top face at -1.5 (flush with the cage plate top), neck through the riser to the TEC
    block=(-1.5, 11.5, 0.6, 5.4), block_z_top=-1.5, tec_z=-12.0,        # neck bottom = TEC cold face
    vac_stub=(3.0, -6.0, 1.5, -9.5),                                   # (Y, Z, dia, X end): stub tube out of the -X face
    therm=(3.0, -6.0, 1.0, 5.0),                                       # (Y, Z, dia, depth) thermistor bore from +X
    # --- cage (Semitron ESd 480) and its corner blocks ---
    cage=(-2.5, 12.5, -2.0, 8.0, -4.5, -1.5),
    post_z1=0.30, post_z0=-1.5,        # block tops 0.30: 0.09 below the fiber envelope (dia 0.125 at Z 0.5, +0.05) so a fiber aligned to a
                                       # waveguide near the die end passes over the corner guards; still cages the 0.5 mm die
    stop_x=10.0, pad_t=0.6, pad_y=((0.6, 1.2), (4.8, 5.4)), relief=0.2,
    guard_gap=0.4,
    yguard_gap=0.6, yguard_t=0.4, yguard_len=1.5,
    # --- riser / heat sink: neck no wider than the cage in Y down to below the holders, then wide ---
    neck=(-8.0, 18.0, -2.0, 8.0), neck_bottom=-12.0,                   # neck Y = cage Y; holders bottom out at -8
    wide=(-14.0, 24.0, -16.0, 22.0), wide_top=-12.0,                   # 38 sq: covers the KXC04015 table's 32 mm bolt grid
    tec=(15.0, 15.0, 2.5), tec_c=(5.0, 3.0),                           # 15 x 15 x 2.5 micro-TEC centred under the die
    # --- push-to-stop ---
    place_short=0.2, push_overtravel=0.10,
    # --- die stage stack under the riser (bottom up), all centred on the die centre (X 5, Y 3) ---
    adapter_t=3.0,                                                      # 6061 adapter plate KB1X1 -> KXC04015-C base (bolt-pattern change)
    spacer_t=8.0,                                                       # 6061 spacer between the X-stage table and the rotary: the rotary's worm
                                                                        # housing starts 2.6 above its base and its cable lead-out dips 2.1 below
                                                                        # it, while the KXC motor box stands 4 above the table top -> 8 mm lifts
                                                                        # the cable 1.9 and the housing 6.6 clear of the motor box at every X offset
    # MISUMI RMPG40W-N (from the vendor STEP): body 40 (X) x 55 (Y) x 35 tall, rotation axis 20 from the short end / 35 from the motor
    # end; 39 sq table 6.5 thick with 8 x M2 on a 10 mm grid + dia 8 bore; base 4 x M3 cbore on 32 x 32 around the axis (bolted from
    # above); worm housing + 28 sq stepper along the body's +X (motor centre 24 from the axis toward the long end), cable dia 14 to X 184
    rot=dict(w=40.0, len_short=20.0, len_long=35.0, h=35.0, table=39.0, table_t=6.5, worm=(20.0, 42.0), motor=(42.0, 59.5), motor_sq=28.0,
             motor_off=24.0, cable=(60.0, 100.0), cable_d=14.0, motor_side=-1),   # motor_side: the long end / motor go to station -Y
                                                                        # cable: only the 40 mm straight lead-out is modelled; the vendor file
                                                                        # draws it straight to 184 (station X -179), which would run into the
                                                                        # Y-stage riser at X < -150 -> route it down/along -Y after the lead-out
    kxc=dict(table=40.0, h=30.0, base_h=21.0, base_len=43.5, overhang=3.5,    # Suruga KXC04015-C (catalog p.1-132): 40 sq table, 30 tall,
             motor_len=59.0, coupling_len=12.0, coupling_h=15.0,        # 59 mm motor section: 12 mm coupling housing (15 tall, the table
             motor_w=28.0, motor_z=(4.0, 34.0), knob_len=4.0, knob_dia=12.0,   # passes over it) + 47 mm motor box 28 wide, 4..34 tall (above the table top!)
             travel=15.0, mount_pitch=32.0, table_t=9.0),               # 15 mm travel (+/-7.5), M3 on a 32 mm grid top and bottom
    stage_step_used=4.0,                                                # device stepping actually used: +/-4 mm (waveguides at die X 1..9 under a fiber at X 5)
)
DIE_CX, DIE_CY = L / 2, W / 2


# ----------------------------------------------------------------------------
# Parts
# ----------------------------------------------------------------------------
def chuck():
    """Copper chuck: pad island on the block top, vacuum holes + plenum, neck to the TEC, vacuum stub, thermistor bore."""
    bx0, bx1, by0, by1 = N["block"]
    z_top, z_tec = N["block_z_top"], N["tec_z"]
    c = box(bx0, bx1, by0, by1, z_tec, z_top)
    px0, px1, py0, py1 = N["pad"]
    c = c.union(box(px0, px1, py0, py1, N["pad_z"][0], N["pad_z"][1]))
    c = c.cut(box(*N["plenum"]))
    for (x, y) in N["vac_holes"]:
        c = c.cut(cyl_z(x, y, N["plenum"][5] - 0.1, N["pad_z"][1] + 0.1, N["vac_d"] / 2))
    vy, vz, vd, vxe = N["vac_stub"]
    c = c.cut(cyl_x(vy, vz, bx0 - 0.1, 5.0, vd / 2))                      # bore from the -X face to under the plenum
    c = c.cut(cyl_z(5.0, vy, vz, N["plenum"][4] + 0.1, vd / 2))            # up into the plenum
    c = c.union(cyl_x(vy, vz, vxe, bx0 + 0.01, vd / 2 + 0.5).cut(cyl_x(vy, vz, vxe - 0.1, bx0 + 0.1, vd / 2)))   # stub tube
    ty, tz, td, tdepth = N["therm"]
    c = c.cut(cyl_x(ty, tz, bx1 - tdepth, bx1 + 0.1, td / 2))
    return c


def corner_block(sx, sy):
    """One corner block; sx = +1 for the +X (stop) end, -1 for the -X (guard) end; sy = +1 for +Y, -1 for -Y.
    Bar along Y on the end-face side with a contact face only in the pad zone (relief elsewhere), plus a
    leg along X outside the facet plane (Y guard). Returns (bar, leg)."""
    z0, z1 = N["post_z0"], N["post_z1"]
    t = N["pad_t"]
    if sx > 0:
        face = N["stop_x"]; xb0, xb1 = face, face + t
    else:
        face = -N["guard_gap"]; xb0, xb1 = face - t, face
    (pa, pb) = N["pad_y"][1] if sy > 0 else N["pad_y"][0]
    yg = W + N["yguard_gap"] if sy > 0 else -N["yguard_gap"]
    yo = yg + N["yguard_t"] * sy
    ylo, yhi = (pa, yo) if sy > 0 else (yo, pb)
    bar = box(xb0, xb1, ylo, yhi, z0, z1)
    if sy > 0:
        rel = box(face - 1 if sx < 0 else face, face + 1 if sx > 0 else face, pb, yhi + 0.1, z0 - 0.1, z1 + 0.1)
    else:
        rel = box(face - 1 if sx < 0 else face, face + 1 if sx > 0 else face, ylo - 0.1, pa, z0 - 0.1, z1 + 0.1)
    rel = rel.intersect(box(min(face, face + sx * N["relief"]), max(face, face + sx * N["relief"]), -10, 20, z0 - 1, z1 + 1))
    bar = bar.cut(rel)
    if sx > 0:
        lx0, lx1 = L - N["yguard_len"] + 1.0, xb1
    else:
        lx0, lx1 = xb0, N["yguard_len"] - 1.0
    leg = box(lx0, lx1, min(yg, yo), max(yg, yo), z0, z1)
    return bar, leg


def cage():
    x0, x1, y0, y1, z0, z1 = N["cage"]
    c = box(x0, x1, y0, y1, z0, z1)
    bx0, bx1, by0, by1 = N["block"]
    c = c.cut(box(bx0 - 0.05, bx1 + 0.05, by0 - 0.05, by1 + 0.05, z0 - 0.1, z1 + 0.1))   # window for the copper block
    for sx in (-1, 1):
        for sy in (-1, 1):
            bar, leg = corner_block(sx, sy)
            c = c.union(bar).union(leg)
    for (x, y) in ((-1.8, -1.2), (11.8, 7.2)):                                   # 2 x M2 to the riser
        c = c.cut(cyl_z(x, y, z0 - 0.1, z1 + 0.1, 1.1))
    for (x, y) in ((11.8, -1.2), (-1.8, 7.2)):                                   # 2 x dia 1.5 dowels
        c = c.cut(cyl_z(x, y, z0 - 0.1, z1 + 0.1, 0.75))
    return c


def cage_parts():
    x0, x1, y0, y1, z0, z1 = N["cage"]
    parts = [box(x0, x1, y0, y1, z0, z1)]
    for sx in (-1, 1):
        for sy in (-1, 1):
            parts += list(corner_block(sx, sy))
    return parts


def tec():
    w, d, h = N["tec"]; cx_, cy_ = N["tec_c"]
    return box(cx_ - w / 2, cx_ + w / 2, cy_ - d / 2, cy_ + d / 2, N["tec_z"] - h, N["tec_z"])


def levels(table_z=C.TABLE_Z, kb_top=None):
    """Z of every interface in the die-stage stack (bottom up): table, KB1X1, adapter, KXC04015-C, RMPG40W-N, riser base."""
    kb_top = table_z + C.KB1X1_H if kb_top is None else kb_top
    z = {"table": table_z, "kb_top": kb_top, "ad1_top": kb_top + N["adapter_t"]}
    z["kxc_bottom"] = z["ad1_top"]
    z["kxc_base_top"] = z["kxc_bottom"] + N["kxc"]["base_h"]
    z["kxc_top"] = z["kxc_bottom"] + N["kxc"]["h"]                     # X-stage table top
    z["spacer_top"] = z["kxc_top"] + N["spacer_t"]
    z["rot_bottom"] = z["spacer_top"]                                  # rotary base on the spacer
    z["rot_top"] = z["rot_bottom"] + N["rot"]["h"]                      # rotary table top = riser base
    z["stage_top"] = z["rot_top"]
    return z


def adapter_kb_kxc(z0):
    """Plate on the KB1X1 top platform (25.4 sq) carrying the KXC04015-C base: 4 x M3 tapped on the stage's 32 x 32 pattern
    (dia 3.5 through holes in the base, confirmed in the vendor STEP), 4 x clearance for the KB1X1 platform screws (pattern to confirm)."""
    t = N["adapter_t"]; k = N["kxc"]["table"]
    a = box(DIE_CX - k / 2, DIE_CX + k / 2, DIE_CY - k / 2, DIE_CY + k / 2, z0, z0 + t)
    p = N["kxc"]["mount_pitch"] / 2
    for dx in (-p, p):
        for dy in (-p, p):
            a = a.cut(cyl_z(DIE_CX + dx, DIE_CY + dy, z0 - 0.1, z0 + t + 0.1, 1.25))
    for dx in (-8, 8):
        for dy in (-8, 8):
            a = a.cut(cyl_z(DIE_CX + dx, DIE_CY + dy, z0 - 0.1, z0 + t + 0.1, 1.7))
    return a


def spacer_kxc_rot(z0, x_off=0.0):
    """8 mm plate on the X-stage table under the rotary: 4 x dia 3.4 through at (+/-16, +/-16) for the rotary's M3 bolts into the
    table's M3 grid, dia 4 H7 dowel at the centre (X-stage pin hole -> rotary bore) so the rotation axis is on the die centre."""
    t = N["spacer_t"]; k = N["kxc"]["table"]
    a = box(DIE_CX - k / 2, DIE_CX + k / 2, DIE_CY - k / 2, DIE_CY + k / 2, z0, z0 + t)
    for dx in (-16, 16):
        for dy in (-16, 16):
            a = a.cut(cyl_z(DIE_CX + dx, DIE_CY + dy, z0 - 0.1, z0 + t + 0.1, 1.7))
    a = a.cut(cyl_z(DIE_CX, DIE_CY, z0 - 0.1, z0 + t + 0.1, 2.0))
    return a.translate((x_off, 0, 0))


def _rot_frame(w, z0):
    """Vendor RMPG40W-N file frame (X = worm/motor direction, Y = rotation axis (table at +Y), Z = body length with the axis at Z -24)
    -> station: axis vertical through the die centre, motor toward -X, long end toward motor_side * Y."""
    sgn = N["rot"]["motor_side"]
    w = w.rotate((0, 0, 0), (1, 0, 0), 90)                      # (x, y, z) -> (x, -z, y): axis up
    w = w.rotate((0, 0, 0), (0, 0, 1), 180)                     # -> (-x, z, y): motor toward -X, long end (+z) toward +Y
    if sgn < 0:
        w = w.mirror("XZ")                                      # long end toward -Y instead
    return w.translate((DIE_CX, DIE_CY + sgn * 24.0, z0 + 16.5))   # file axis lands at Y -/+24 after the rotations / mirror


def rmpg40w(z0, x_off=0.0):
    """MISUMI RMPG40W-N envelope in the station frame: body, table, worm housing, motor, cable. Base face at z0, table top at z0 + 35.
    Rides on the X stage: x_off shifts everything along X."""
    r = N["rot"]; sgn = r["motor_side"]
    yl = DIE_CY + sgn * r["len_long"]; ys = DIE_CY - sgn * r["len_short"]
    y0, y1 = min(yl, ys), max(yl, ys)
    body = box(DIE_CX - r["w"] / 2, DIE_CX + r["w"] / 2, y0, y1, z0, z0 + r["h"] - r["table_t"])
    body = body.cut(cyl_z(DIE_CX, DIE_CY, z0 - 0.1, z0 + r["h"] + 0.1, 4.0))
    t = r["table"]
    table = box(DIE_CX - t / 2, DIE_CX + t / 2, DIE_CY - t / 2, DIE_CY + t / 2, z0 + r["h"] - r["table_t"], z0 + r["h"])
    for dx in (-10, 0, 10):
        for dy in (-10, 0, 10):
            table = table.cut(cyl_z(DIE_CX + dx, DIE_CY + dy, z0 + r["h"] - 3.7, z0 + r["h"] + 0.1, 4.0 if (dx == 0 and dy == 0) else 0.8))
    ym = DIE_CY + sgn * r["motor_off"]; ms = r["motor_sq"] / 2; zc = z0 + 16.5
    worm = box(DIE_CX - r["worm"][1], DIE_CX - r["worm"][0], ym - 14, ym + 14, zc - 14, zc + 14)
    motor = box(DIE_CX - r["motor"][1], DIE_CX - r["motor"][0], ym - ms, ym + ms, zc - ms, zc + ms)
    cable = cyl_x(ym - sgn * 5.5, zc - 11.6, DIE_CX - r["cable"][1], DIE_CX - r["cable"][0], r["cable_d"] / 2)
    d = {"body": body, "table": table, "worm": worm, "motor": motor, "cable": cable}
    return {k: v.translate((x_off, 0, 0)) for k, v in d.items()} if x_off else d


def rmpg40w_vendor(z0, x_off=0.0, path=None):
    """MISUMI RMPG40W-N from the vendor STEP (cad/vendor/misumi_RMPG40W-N.step, git-ignored). 5 solids: body (with worm housing,
    motor, cable), table plate, three M3 fixing bolts. Split by bounding box; bolts merged into the body. Returns the same dict
    as rmpg40w() (worm/motor/cable are the body's sub-boxes for the checks) or None."""
    path = path or C.vendor_path("misumi_RMPG40W-N.step")
    if not os.path.exists(path):
        return None
    wp = cq.importers.importStep(path)
    sol = sorted(wp.solids().vals(), key=lambda t: -t.Volume())
    body = _rot_frame(cq.Workplane().add(sol[0]), z0)
    body = body.cut(box(DIE_CX - 400, DIE_CX - N["rot"]["cable"][1], -100, 100, z0 - 50, z0 + 100))   # drop the straight cable past the lead-out
    table = _rot_frame(cq.Workplane().add(sol[1]), z0)
    bolts = _rot_frame(cq.Workplane().add(cq.Compound.makeCompound(sol[2:])), z0)
    env = rmpg40w(z0)
    d = {"body": body, "table": table, "bolts": bolts, "worm": body.intersect(env["worm"]), "motor": body.intersect(env["motor"]),
         "cable": body.intersect(box(*[c for pair in zip(bb(env["cable"])[0::2], bb(env["cable"])[1::2]) for c in pair]))}
    return {k: v.translate((x_off, 0, 0)) for k, v in d.items()} if x_off else d


def kxc04015(z0, x_off=0.0):
    """Suruga KXC04015-C envelope with its table at X offset x_off (0 = home, +/-7.5 travel). Motor section toward -X.
    Returns dict: base, table, motor, knob. Base 40 wide x 43.5 long (3.5 overhang at the far +X end), 21 tall; table 40 sq, top at z0 + 30."""
    k = N["kxc"]; t = k["table"]
    x0, x1 = DIE_CX - t / 2, DIE_CX + t / 2
    y0, y1 = DIE_CY - t / 2, DIE_CY + t / 2
    base = box(x0, x1 + k["overhang"], y0, y1, z0, z0 + k["base_h"])
    for dx in (-k["mount_pitch"] / 2, k["mount_pitch"] / 2):                     # 4 x dia 3.5 through, cbore, on the 32 grid
        for dy in (-k["mount_pitch"] / 2, k["mount_pitch"] / 2):
            base = base.cut(cyl_z(DIE_CX + dx, DIE_CY + dy, z0 - 0.1, z0 + k["base_h"] + 0.1, 1.75))
    table = box(x0 + x_off, x1 + x_off, y0, y1, z0 + k["h"] - k["table_t"], z0 + k["h"])
    for dx in (-16, 0, 16):                                                       # 8 x M3 on the 16 grid (centre = dia 4 H7 pin)
        for dy in (-16, 0, 16):
            table = table.cut(cyl_z(DIE_CX + x_off + dx, DIE_CY + dy, z0 + k["h"] - 4.1, z0 + k["h"] + 0.1, 1.25 if (dx or dy) else 2.0))
    mw = k["motor_w"]
    coupling = box(x0 - k["coupling_len"], x0, DIE_CY - mw / 2, DIE_CY + mw / 2, z0, z0 + k["coupling_h"])
    motor = box(x0 - k["motor_len"], x0 - k["coupling_len"], DIE_CY - mw / 2, DIE_CY + mw / 2, z0 + k["motor_z"][0], z0 + k["motor_z"][1])
    zk = z0 + (k["motor_z"][0] + k["motor_z"][1]) / 2 + 3
    knob = cyl_x(DIE_CY, zk, x0 - k["motor_len"] - k["knob_len"], x0 - k["motor_len"] + 0.01, k["knob_dia"] / 2)
    return {"base": base, "table": table, "coupling": coupling, "motor": motor, "knob": knob}


def kxc04015_vendor(z0, x_off=0.0, path=None):
    """Suruga KXC04015-C from the vendor STEP (cad/vendor/suruga_KXC04015-C.step, git-ignored). File frame: X = travel
    (motor at +X), Y = up (base bottom Y 0, table top Y 30), Z = width (+/-20), table drawn at mid travel. Confirmed from the
    file: table 8 x M3 on a 16 mm grid + dia 4 centre pin; base 4 x dia 3.5 through on 32 x 32 + dia 4 centre + one dia 5 at
    (27.5, 4); base solid runs to X 31 (sensor cover), motor box 28 sq x 38 long at X 41..79, 34 tall (4 above the table top).
    Station frame: X = -file X (motor toward -X), Y = file Z, Z = file Y. Returns the same dict as kxc04015() or None."""
    path = path or C.vendor_path("suruga_KXC04015-C.step")
    if not os.path.exists(path):
        return None
    wp = cq.importers.importStep(path)
    parts = {}
    for t in wp.solids().vals():
        b = t.BoundingBox()
        if b.ymin > 15 and b.xmax < 25:
            k = "table"
        elif b.xmin > 40:
            k = "motor"
        elif b.xmax <= 31.5 and b.ymin < 1:
            k = "base"
        else:
            k = "coupling"
        w = cq.Workplane().add(t).rotate((0, 0, 0), (1, 0, 0), 90).rotate((0, 0, 0), (0, 0, 1), 180)   # (x, y, z) -> (-x, z, y)
        w = w.translate((DIE_CX + (x_off if k == "table" else 0.0), DIE_CY, z0))
        parts[k] = w
    parts["knob"] = parts["coupling"]                                                                  # knob/cable are in the coupling solid
    return parts
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

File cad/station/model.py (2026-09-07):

"""
Full test-station assembly: nest, gripper module, bench-level Cartesian transport
(X axis + Z axis + arm, Y stage under the stick), two NanoMax 300 fiber stages with
holders, microscope column/objective, optical table. Frame, die and contact rules: cad/common
(X = die long axis, Y = optical axis, Z up, Z = 0 = die bottom at the nest). The gripper, the nest and
the tray are imported from their own packages (cad/gripper, cad/nest, cad/tray); this file only
places them and adds the transport, the fiber stages and the microscope.

Bought parts: vendor STEP from cad/vendor (git-ignored, see vendor/README.md) wherever the file is present,
the envelope below otherwise (so a clone without the vendor files still builds and checks):
  - MISUMI LX20 single-axis actuators (X, Y, Z transport): envelope from common.LX20 until the STEP is supplied
  - Thorlabs NanoMax 300: 112 x 112 footprint, 62.5 deck height, 4 mm travel
  - Microscope: objective barrel dia 34, tube dia 40, column post dia 40 behind (+X)  (always an envelope)

Transport layout (see station/README.md): the X actuator runs along X beside the input NanoMax at Y -140, on a
full-length riser, its 52 mm band outside the tray's Y sweep so no bridge is needed; the Z actuator stands on an
angle bracket on the X block with its motor up; the 25 mm square arm leaves an adapter plate on the Z block along
+Y to the gripper interface. The Y actuator sits under the tray on a riser that puts the pocket ledges 12 mm below
the chuck pad, so Z uses 8 mm lift + 12 mm drop of its 36.5 mm stroke.

Run: python cad/station/model.py [--horizontal]
     -> STEP/station_assembly[_h].step (git-ignored, large) + checks[_h].txt (the header lists the vendor files placed)
"""
from __future__ import annotations
import os, sys
import cadquery as cq

sys.path.insert(0, os.path.dirname(os.path.dirname(os.path.abspath(__file__))))   # cad/
import common as C                                                             # noqa: E402
from common import box, bb, gap, gap_any, gap_cyl                              # noqa: E402
from gripper import model as G                                                 # noqa: E402
from nest import model as NM                                                   # noqa: E402
from tray import model as TM                                                   # noqa: E402

DIRS = C.out_dirs(__file__)
VENDOR_PLACED = []                           # names of the manufacturer files actually placed (written into the checks header)


def vendor_step(fname):
    """Manufacturer STEP from cad/vendor/ when the file exists, else None (caller falls back to its envelope)."""
    p = C.vendor_path(fname)
    if os.path.exists(p):
        print(f"[vendor] {fname}")
        VENDOR_PLACED.append(fname)
        return cq.importers.importStep(p)
    return None

# ----------------------------------------------------------------------------
# Station parameters
# ----------------------------------------------------------------------------
S = dict(
    # fiber side: bench levels from common (TABLE_Z follows from these)
    holder_axis_above_deck=C.HOLDER_AXIS_ABOVE_DECK,   # fiber axis height above the NanoMax top platform (holder-dependent; measure)
    nanomax_w=C.NANOMAX["w"], nanomax_h=C.NANOMAX["h"], nanomax_platform_h=C.NANOMAX["platform_h"], nanomax_gap_y=C.NANOMAX["gap_y"],
    # fiber holder envelope: single source common.FIBER (shared with the nest)
    fiber_protrusion=C.FIBER["protrusion"], holder_w=C.FIBER["holder_w"], holder_zb=C.FIBER["holder_zb"],
    holder_zt=C.FIBER["holder_zt"], holder_len=C.FIBER["holder_len"],
    # microscope (behind the nest, +X, as in the bench photo); WD and diameters from common
    obj_wd=C.OBJ_WD, obj_dia=C.OBJ_DIA, obj_len=40.0, tube_dia=C.TUBE_DIA, tube_len=60.0,
    column_x=80.0, column_dia=40.0, column_top=260.0,
    # transport: three MISUMI LX2005-B1-T2042 actuators (common.LX20), lead 5
    lx_L=dict(x=300, y=200, z=100),   # base lengths -> effective strokes 236.5 / 136.5 / 36.5 (common.LX20["stroke"])
    x_axis_cy=-140.0,              # X actuator centre-line: its 52 mm band (Y -166..-114) lies beside the tray's Y sweep (deck to
                                   # Y -108 at the extreme row) and beside the input NanoMax (X -51..61), so the riser is one bar
    nanomax_riser=C.NANOMAX_RISER, # plate under each NanoMax (the die-stage stack needs 100 mm under the die; the fiber axis stays at Z 0.5)
    tray_drop=12.0,                # pocket ledge top below the chuck pad top: Z uses 8 mm lift + 12 mm drop of its stroke
    push_x=1.7,                    # push-to-stop travel at the nest (docs/pick_and_place_design.md 3.3)
    end_margin=2.5,                # block-centre margin kept to both travel limits of every actuator
    tower_w=60.0, tower_t=10.0,    # 6061 angle bracket on the X block: 60 x 60 x 10 base plate (block's 4 x M4), 10 mm vertical leg
    arm_sec=25.0,                  # square arm bar (6061) from the adapter plate on the Z block to the gripper interface
    arm_plate_t=8.0,               # adapter plate on the Z block face (block's 4 x M4)
    tower_mass=1.7,                # kg: Z actuator 0.45 + brake motor 0.6 + bracket 0.3 + arm 0.25 + gripper 0.1 (moment check on the X block)
    # wafer tray: geometry and column positions live in cad/tray (TM.TR)
    tray_cols=TM.TR["cols"], tray_rows=TM.TR["rows"], tray_col_pitch=TM.TR["col_pitch"], tray_row_pitch=TM.TR["row_pitch"],
    tray_col0_x=TM.TR["col0_x"],   # die X of the first (nearest) column; last column at -95 - 7*16 = -207
)

die_top = G.die_top
table_z = C.TABLE_Z                                                                          # -86.0 (single source: common)
cy = G.die_cy                                                                                # 3.0
S["table_z"] = table_z


# ----------------------------------------------------------------------------
# Static structure
# ----------------------------------------------------------------------------
def table():
    return box(-720, 220, -280, 280, table_z - 12, table_z)
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

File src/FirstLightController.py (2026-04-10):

import numpy as np
from typing import *
import plotly.graph_objects as go
from threading import Thread
from scipy.optimize import curve_fit
from scipy.stats import multivariate_normal
import itertools
import time
from tqdm import tqdm
from pprint import pprint

from src.DieTesterInstrument import SurugaSeikiDS102, DieTesterStage
from src.NIDAQPowermeter import PowermeterSystem

class FirstLightController:
    axis_convention = ['X', 'Y', 'Z']

    def __init__(self, pm: PowermeterSystem, die_tester_stage: DieTesterStage):
        """
        Controller for the first light search.
        """
        self.pgen = PathGenerator()
        self.flo = FirstLightOptimizer()
        self.pm = pm
        self.stg = die_tester_stage
    
    def unpackbits(self, x, num_bits):
        """Little-endian 1d uint array -> 2d array of bit arrays. Returns copy of the array with numbers replaced by bitstrings"""

        assert not np.issubdtype(x.dtype, np.floating), "Numpy data type must be int-like."

        xshape = list(x.shape)
        x = x.reshape([-1, 1])
        mask = 2**np.arange(num_bits, dtype=x.dtype).reshape([1, num_bits])
        return (x & mask).astype(bool).astype(int).reshape(xshape + [num_bits])
    
    def scan_path(self, stage, commands, speed_setting, line_numbers: int, **kwargs): # TODO
        """
        Scan a path given by a list of commands specifying relative coordinates. 
            stage: 'l' or 'r'.
            commands: Of the form (axis, distance), e.g. ('X', 10.0)
            speed_setting: speed setting of the device during travel
            line_numbers: line (or lines for XZ motion) on the DAQ port containing the device's motion output (0-32)
            kwargs:
                - perform_regression: Defaults to True. Whether to perform the gaussian regression and return the mean and cov.
                - samples_per_call: the number of samples captured before a motion callback. By default is a tenth of per second sample rate (0.1s callback).
                - return_to_origin: Defaults to True. Whether to return to the inital position where the scan was begun.
                - ls_params: Defaults to None. Initial parameters for gaussian least-squares regression, if necessary.
                - ls_kwargs: Defaults to None. Kwargs for the least squares regression, like 'method'.
                - minimum_move_time: Determined by the maximum rate that commands can be sent over usb. Defaults to the stage query delay. This is to prevent the code from querying the controller too fast (after short movements.)
                - timeout: Defaults to 3 seconds. Motion timeout in seconds for device to start motion.
                - round_commands: Defaults to True. Whether to round commands on the path to those taken exactly by the device (e.g. 4.077 microns -> 4.05 microns.)
                - figure_axes: Defaults to the axes in the commands (e.g. ['X', 'Y']) (if there's only one, selects the next one in the convention. e.g. 'Z' -> ['Z', 'X'])
        """
        ## Set Variables
        stage = stage.lower()
        assert stage == 'l' or stage == 'r', "Stage must be 'l' or 'r'."
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

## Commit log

2026-04-10 Added Eric's scripts and old Kyungdik's scripts as src and reference folders. Notes consist of the insertion loss measurements.
    [SCG 2026 PPLN IL_TSL770_12dBm_1560nm.xlsx, SCG 2026 PPLN IL_TSL770_12dBm_1560nm_ver2.xlsx, insertion_loss_device43.csv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]
2026-06-05 updated file saving - transfer function and insertion loss in the same script
2026-08-20 Added input power characterization_data folder
    [boa.xlsx, lut.csv, lut770_aftBOA267mA.csv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]
2026-08-20 Added GUI for raster and z-scan.
    Added a line if z-fit returns less than -3 value, set it to -1. This should avoid the fiber focus moving away that we observed during the auto-alignment runs. Added custom chip movement in GUI for coarse fiber control
    [AutoAlignController.py, ScanGUI.py, StageControlGUI.py]
2026-08-23 Add die handling and edge-coupled testing concept study
    Concept study responding to the mechanical design brief for
    high-throughput handling of singulated 10 x 6 mm photonic dies:
    - Grounds requirements in the existing tester hardware/software
    (DS102 stages, center X+theta axis, vision angle calibration,
    automated first light and full-chip stepping).
    - Defines shared building blocks: self-registering precision nest
    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
2026-08-23 Reframe concept study as full-system redesign for batch testing
    Rev. 2 of the die handling study, per review feedback:
    - Reframed from retrofitting the existing single-die stage stack to a
    ground-up system redesign targeting hundreds of dies per campaign
    and unattended (lights-out) operation.
    - Removed the carousel concept.
    - Precision philosophy: dumb dense storage, coarse transfer, and a
    single self-registering precision nest at the optical site, instead
    of replicated precision carriers.
    - Scaled concepts: carrier hotel + gantry pick-and-place into one
    fixed nest (recommended), pallet cassette line, batch comb plates
    as a semi-automated stepping stone, and a clean-sheet evalua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
2026-09-05 Fold as-built bench observations into the redesign study
    - Add reference photo of the current manual setup (docs/images).
    - Appendix A: as-built observations (enclosure, overhead objective,
    fiber holder arms through slotted walls, loose fiber/cable dressing,
    individually table-mounted components) and their design consequences.
    - Nest section: size the +/-Y corridors from the fiber-arm envelope,
    fix +/-X as the die-exchange approach direction, lower the nest onto
    the common base.
    - Recommended system: vision-column clearance options (retract vs long
    working distance), side-entering end-effector along X, hotel placed
    along X, cell-scale enclosure and captive fiber routing, single b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
2026-09-05 Backside-only handling: vision-registered nest, SCARA + vacuum tongue, slotted sticks
    Rev. 2.2 of the redesign study. The dies carry air-clad ridge
    waveguides (no top oxide), so no top-surface or facet contact is
    permitted anywhere in the handling chain.
    - Nest: two backside vacuum rails ~1 mm inboard of each facet with an
    open channel between them; Z/pitch/roll mechanical, X/Y/theta by
    overhead vision plus the X-Y-theta correction stage. Facet-face and
    end-face datums dropped from the baseline (end-face pins kept as an
    optional add-on).
    - New section 6a: pick-and-place selection. 4-axis SCARA on an
    off-table pedestal carrying a thin backside vacuum tongue that slides
    under the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
2026-09-05 Add tape-to-stick sorting step for dies delivered diced on tape
    Rev. 2.3 of the redesign study. Dies arrive on dicing tape on a film
    frame with kerf-width streets, which no backside tool can pick from.
    - New section 6b: separate off-tester sorting step - UV-release tape,
    film-frame expansion to open streets to ~1 mm, backside pin ejector,
    end-face edge gripper with stepped jaws, wafer map to stick map for
    die ID and orientation. Bench station, commercial die sorter with an
    edge-grip head, or vendor delivery into sticks as options; film frame
    deliberately not integrated into the tester.
    - Records the edge gripper as a candidate to replace the tongue on the
    tester, decided after s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
2026-09-05 Edge gripper everywhere; add sorting-station and gripper geometry sketches
    Rev. 2.4 of the redesign study.
    - Decision: one stepped-jaw end-face edge gripper for every handling
    step (tape pick, nest exchange, binning); backside vacuum tongue
    demoted to a documented fallback. Rationale and explicit why-not
    table in section 6a; numbers for contact pressure, buckling and
    friction hold.
    - Nest: jaw clearance requirement at both die ends, rail gap kept open
    for the fallback; exchange sequence rewritten for the gripper.
    - Sticks: backside ledges plus end-face jaw slots, 7.5 mm pitch.
    - Section 6b: sorting-station layout and pick geometry described
    around the new figures; sorter trial i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
2026-09-05 Add month-1 prototype plan for robotic die exchange
    What to prototype first (gripper + nest + stick contact system, hand
    cycled before the robot arrives), then stick-to-nest-to-stick cycling
    on a Dobot MG400, then integration at the optical station with fibers
    and real scrap dies. Parts list with alternatives, costs and lead
    times; week-by-week schedule for two people; pass criteria; software
    modules to add to this repo; risks and fallbacks. Tape pick deferred
    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
2026-09-05 Add month-1 bill of materials and die-sorting outsourcing decision
    Orderable BOM for the robotic die-exchange prototype: day-1 orders
    (Dobot MG400, SMC MHZ2-6D gripper with position switches, custom
    flexure fingers in Semitron ESd 480, lapped test nest, SLA sticks,
    compressor/vacuum if needed, Si and LN blank dies diced on UV tape,
    bench ionizer), week-1 pneumatics and rig parts with part numbers and
    checked prices, and price-checked month-2 items (Epson T3-B, Dynatex
    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
2026-09-05 Replace SCARA/MG400 with a bench-level 3-axis Cartesian for the tester
    Correction after review: the Dobot MG400 is an articulated desktop
    arm (J2/J3 pitch in a vertical plane), not a horizontal-plane SCARA,
    so it approaches the nest from above and behind, into the microscope
    column's volume. A true SCARA's vertical quill lands at the die end
    where the objective barrel is. The gripper must enter a straight
    ~13 mm corridor under the objective along die X, which is a linear
    axis task.
    - Concept study rev. 2.5: transfer axes = bench-level 3-axis
    Cartesian from motorized linear stages (Zaber X-LSM, Thorlabs
    LTS150, or Suruga stages on a DS102); SCARA only with an offset
    bar; articulated ar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
2026-09-05 3D model: Cartesian transfer axes, offset gripper module, swing-away objective option
    - Nest scene now shows the bench-level X axis, Z axis and arm at -X,
    the stick on a Y stage, the gripper module with its actuator body
    outside the objective footprint and thin cantilever finger bars
    entering under the objective; carry sequence goes to the stick.
    - New parameter: objective swings away on a motorized column pivot
    during exchange; readouts and label reflect it.
    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
2026-09-05 3D model: Cartesian axes, offset gripper, swing-away objective, legible nest scene
    - Nest scene rebuilt around the bench-level Cartesian: fixed X axis,
    Z axis, moving carriages and arm, stick on a Y stage; sequence now
    carries the die 160 mm to the stick and sets it down.
    - Gripper module redrawn as offset actuator with two thin cantilever
    finger bars; only the bars enter the objective footprint.
    - Objective translucent; keep-out volume under the objective drawn
    explicitly; optional motorized swing-away pivot with readouts.
    - Legibility: color-coded fixed vs moving structure, on-canvas step
    banner, camera follows the die, close-up / whole-station presets,
    key legend, fewer labels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
2026-09-05 Add parametric CAD package for the end-face gripper module
    CadQuery model (docs/cad/gripper_module.py) generating STEP and STL
    for the custom parts - rigid far arm, compliant near arm, two Semitron
    ESd 480 tip blocks, 0.127 mm spring-steel flexure blade, L-bracket
    with the 25 x 25 mm M4 interface - plus a STEP assembly with a
    dimensionally faithful SMC MHZ2-6D stand-in (from the SMC catalog
    drawing), the die, nest rails and an objective keep-out cylinder.
    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
    [bracket_6061.step, bracket_6061.stl, far_arm_6061.step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]
2026-09-05 Add full station CAD assembly with clearance checks and movement pattern
    station_assembly.py builds the complete test station in the gripper
    frame: nest on a kinematic base, gripper module, bench-level Cartesian
    transport (X axis on a riser above the NanoMax envelope, Z tower,
    L-arm, Y stage under the stick), two Thorlabs NanoMax 300 fiber stages
    with holder arms and fibers, microscope column at +X with objective and
    tube, optical table. Exports STEP, plan/front/side/iso and nest
    close-up SVG views, and station_checks.txt with AABB and cylinder-aware
    clearances for the nest and stick configurations plus swept volumes.
    Design changes driven by the checks: actuator moved to X -30 and the
    brac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
    [bracket_6061.step, bracket_6061.stl, far_arm_6061.step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]
2026-09-05 CAD README: update actuator and bracket extents after the tube-clearance move
    Claude-Session: https://claude.ai/code/session_017s3uYj7PgudCTf2uFjMSCp
2026-09-05 Station CAD: one wafer tray (8 x 14 = 112 pockets) replaces the single stick
    - station_assembly.py: Y stage now carries a 128 x 106 mm wafer tray
    with 8 columns (16 mm pitch along X) x 14 rows (7.5 mm pitch along Y);
    X selects the column, Y the row; the die returns to its own pocket.
    Second checked configuration is the farthest column (X travel used
    262 of 300 mm). Tray built with compound booleans (14 s rebuild).
    - README: container assumption (one wafer = one tray, map-indexed
    pockets, no physical binning at the tester), updated layout table and
    movement pattern.
    - BOM A5 and concept study updated from sticks to wafer trays.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
    [station_assembly.step]
2026-09-05 Tray pockets: +/-1 mm corner retention with nose slots; document why no arm vision
    Pocket cavity 12.0 x 6.8 mm retains the die to +/-1.0 mm in X (inside
    the jaws' +/-1.9 mm capture) with 3.6 mm nose slots in both end walls
    for the open jaws, replacing the plain 14 mm cavity that let the die
    wander past the capture range. README and BOM updated; 4-inch wafer,
    single die orientation recorded.
    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
    [station_assembly.step]
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2026-09-06 Station CAD: place Thorlabs NanoMax 300 and KB1X1 vendor STEP models (--vendor)
    Downloads via docs/cad/vendor/fetch_vendor_step.sh (files git-ignored). The input
    NanoMax is rotated -90 deg so its Z micrometer clears the X axis; clearances
    re-checked with the real stage envelopes (station_checks_vendor.txt). Velmex and
    SMC models need manual download (captcha / account); envelopes remain for them.
    Setup hook now restores the full cadquery-ocp build that cadgen shadows.
    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
2026-09-06 Station CAD: place the Velmex MN10-0150/0050 vendor models; X axis on two pedestals over the Y stage
    - velmex(): split each BiSlide STEP into fixed solids and slider, position sliders
    along the travel; X axis body ends at X -40 above the NanoMax base, riser 86 mm
    as two pedestals with a gap for the Y stage body and tray deck; Z axis vertical on
    the X slider with an adapter plate and drop bar; Y axis under the tray
    - xc_nest -140 (arm reach 140) keeps the real X slider inside its travel at the nest
    - checks: X-axis motor end and riser pedestals separately, deck/tray at the extreme row
    - README layout/vendor tables, BOM part numbers MN10-0150-M02-21 + 2x MN10-0050-M02-21, VXC controller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
    [station_assembly.step]
2026-09-06 Place the SMC MHZ2-6D vendor model; correct finger spacing (8/12 mm is the inner gap)
    The catalogue's closed/open widths are between the finger faces, not outer widths:
    fingers at +/-4..8 mm closed, +/-6..10 open. Arm root plates move 4 mm outward per
    side; nothing changes at the die. Vendor STEP (user-supplied) replaces the envelope in
    the --vendor station build and in a new gripper_module_assembly_vendor.step render.
    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
    [bracket_6061.step, far_arm_6061.step, far_arm_6061.stl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]
2026-09-06 Horizontal actuator layout (--horizontal) with reworked clearance checks
    Gripper module gains a switchable horizontal layout (body along Y at Z 10-20, fingers
    +Y, root plates on the finger faces, flat bracket on the body's vertical M3 threads).
    Station: arm bars cross the X-axis band at arm_cross_z=82 with a drop bar when the
    bracket is lower; Velmex cleats relocated 120 mm; motor end split from the body box;
    checks per arm member and per swept part. Both layouts pass; renders for both.
    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
    [bracket_6061.step, bracket_6061_h.step, bracket_6061_h.stl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]
2026-09-06 Self-registering nest: end-face stop pads, corner cage, push-to-stop sequence
    nest_module.py: 17-4 rail insert, Semitron cage frame with two +X stop pads (X and
    yaw), -X guard and corner Y guards outside the facet planes, riser; clearance checks
    vs the gripper (closed, open, pushing), fiber and holder envelopes. Station uses it;
    X-Y-theta correction stage dropped. Docs and BOM updated.
    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
    [nest_cage_semitron.step, nest_cage_semitron.stl, nest_module_assembly.step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]
2026-09-06 Nest redesign: copper vacuum chuck on a TEC, 10 mm neck for 5 mm fiber protrusion, per-member checks
    - fiber holders come to 5 mm from the facets: nest neck limited to the cage width (Y -2..8) down to
    Z -12, wide body with the 15x15 TEC pocket below the holders' underside
    - lapped copper chuck pad (75 % of the backside) with 6 vacuum holes, plenum, stub tube and
    thermistor bore replaces the two rails; aluminium riser is the hot-side heat sink
    - station holder envelope widened (25 mm, Z -8..+4) and checked per member against the nest
    - docs: CAD README nest section, BOM A4, concept study rev 2.8 pointer
    Claude-Session: https://clau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
    [nest_cage_semitron.step, nest_cage_semitron.stl, nest_chuck_copper.step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]
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2026-09-06 Restructure CAD into one folder per component with a synchronized build
    Move docs/cad into cad/ with one folder per component (gripper, nest, tray,
    station) and a shared cad/common module (frame, die, contact band, fiber-holder
    envelope, box/cylinder helpers, AABB clearance functions, output layout).
    Each model.py writes only into its own folder (STEP/, STL/, renders/,
    checks*.txt) and imports the others as packages; the tray is now its own
    component extracted from the station. cad/build.py rebuilds everything in
    dependency order, renders with cadgen, writes build_manifest.json and fails
    `--check` when a source changed without a full rebuild; the SessionStart hook
    runs that check. Per-compon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
    [bracket_6061.step, bracket_6061.stl, bracket_6061_h.step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]
2026-09-06 Put the nest on a die stage: Suruga KXC04015-C X stage over an RPG38 rotary
    The devices span ~8 mm along the die and the NanoMax fiber stages travel only
    4 mm, so the die must be stepped from device to device by moving the nest, as
    the current tester's centre stage does. cad/nest now builds the stack under
    the riser: KB1X1 (12.7) / 3 mm adapter / Suruga RPG38 rotary (dia 38 x 16,
    micrometer -X, set once for yaw) / 3 mm adapter / Suruga KXC04015-C (40 sq
    table, 30 tall, 15 mm travel, motor section 59 toward -X) with catalog-drawing
    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
    [bracket_6061.step, bracket_6061_h.step, far_arm_6061.step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]
2026-09-06 Motorized yaw: MISUMI RMPG40W-N under the X stage; vendor STEP for both stages; one station build
    Die stage: the user-supplied RMPG40W-N (horizontal-table motorized worm-gear rotary,
    body 40 x 55 x 35, axis 20 from the short end, 39 sq table with 8 x M2 on a 10 mm
    grid, 4 x M3 fixing bolts on 32 x 32, 28 sq stepper) replaces the RPG38 envelope
    under the KXC04015-C; both stages are placed from their vendor STEP (cad/vendor,
    git-ignored) with catalog envelopes as fallback. Motors point -X, the rotary's long
    end -Y; its straight vendor cable is cut after a 40 mm lead-out (it would reach the
    Y-stage riser). The KXC04015-C file confirmed the adapter patterns (table M3 on 16,
    base dia 3.5 on 32).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
    [bracket_6061.step, bracket_6061_h.step, far_arm_6061.step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]
2026-09-06 Rotary on top of the X stage; pick-and-place design note
    Die stage order flipped: KB1X1, 3 mm adapter, KXC04015-C, 8 mm spacer, RMPG40W-N,
    riser. Yaw is measured by driving the X stage from one end fiducial to the other
    under the fixed microscope; that offset is the die's yaw relative to the stage
    travel (the travel's own angle cancels), so the rotary has to turn the die
    relative to the travel, i.e. sit above it. The rotary's 4 x M3 on 32 x 32 match
    the X-stage table grid; the riser now bolts to the rotary's 39 sq table with
    4 x M2 at +/-10; the middle adapter is gone. The 8 mm spacer (centre dowel puts
    the axis on the die centre) is needed because the rotary's worm housing starts
    2.6 above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
    [bracket_6061.step, bracket_6061_h.step, far_arm_6061.step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]
2026-09-06 Crown the gripper noses R 30 mm across the contact band
    gripper: add nose_crown_r=30.0 and intersect both tip-block noses with a
    vertical-axis cylinder so the contact face is crowned across the 3 mm band
    (sag 38 um at the band edges, extents unchanged). checks.txt and checks_h.txt
    now report the crown geometry (squaring couple 390 uN.m per degree of die
    yaw) and the friction-only hold (64 / 192 mN at mu 0.1 / 0.3 vs 1.4 mN die
    weight). README quotes the crown rows.
    docs: pick_and_place_design.md numbers aligned with the checks (sag 38 um,
    0.39 mN.m per degree).
    Full build with vendor files present; STEP/STL, renders and
    build_manifest.json regenerated.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
    [bracket_6061.step, bracket_6061_h.step, far_arm_6061.step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]
2026-09-07 Replace the Velmex transport with three MISUMI LX20 actuators
    station: X, Y and Z axes are now MISUMI LX2005CG-B1 single-axis actuators
    (lead 5, cover, low-particulate grease) placed from the three manufacturer
    STEP files (misumi_LX2005CG-B1-A2040-300/200/100, git-ignored) with an
    envelope fallback; the Velmex code is removed. The X actuator (L 300,
    stroke 236.5, 208.7 used) runs along X at Y -140 on one 118 mm riser bar,
    its band beside the tray's Y sweep, so the two-pedestal bridge is gone; the
    Z actuator (L 100, 20 of 36.5 used, brake motor up) stands on a 60 x 60 x 10
    angle bracket on the X table; the arm is one 25 mm bar along +Y from an
    adapter plate on the Z table (no drop bar); the Y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
    [bracket_6061.step, bracket_6061_h.step, far_arm_6061.step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]
2026-09-07 Decide the stepper route for the LX20 axes: T2042 plate, Oriental Motor AZM46
    docs: BOM A1 now specifies the actuators with the T2042 adapter, AZM46AK (X, Y)
    and AZM46MK with brake (Z), AZD-KD drivers, couplings (dia 4 x dia 6), sensor
    sets and supply; the servo route on the A2040 plate is recorded as rejected.
    Station README, vendor fetch script and the concept study revision line say
    the same; BOM A4 no longer lists a 25 mm Y-stage riser (it is the 63 mm bar
    in B14). No model source changed.
    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
2026-09-07 Model the mounting parts as real parts and add the print list
    station: the risers, tower bracket, arm, tray deck and NanoMax riser plates
    are now parts with bolt patterns (LX20 base holes dia 3.4 in two rows 18 apart
    on a 60 pitch, table plate 4 x M4 on 20 x 45 with two dia 3 dowels, gripper
    interface 4 x M4 on 25 x 25 with two dowels, all read from the vendor STEP and
    the gripper model) exported as STEP + STL: x_axis_riser_6061[_h] (40 wide bar
    with a 60 x 8 slotted foot flange), y_axis_riser_6061 (80 wide flange),
    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
    [arm_6061.step, arm_6061.stl, arm_6061_h.step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]
2026-09-07 Track the manufacturer STEP files in cad/vendor
    The files are needed outside this checkout, so cad/vendor is no longer
    ignored (37 MB, largest the 29.6 MB NanoMax). They remain licensed vendor
    downloads for our own design work; README, CLAUDE.md and cad/README say so.
    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
